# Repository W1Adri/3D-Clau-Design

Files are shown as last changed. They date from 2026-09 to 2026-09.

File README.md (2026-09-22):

# CLAU — Modelo 3D y análisis volumétrico

Modelo 3D paramétrico del CubeSat 6U **CLAU** (*CubeSat Làser per a Aplicacions
Ultrasegures*), de la asociación **ACSAR** (EETAC, UPC).

## La misión en pocas líneas

CLAU demostrará **distribución cuántica de claves (QKD)** desde órbita baja hacia
la estación óptica terrestre **ESA OGS Teide** (telescopio de 1 m). Protocolo
**BB84 con estados señuelo (decoy)**, codificación en **polarización**, a
**1550 nm**.

**Arquitectura "opción B"** (19-09-2026): el transmisor BB84 se construye con
componentes de **fibra comerciales** — láser DFB pulsado más moduladores de
niobato de litio —, **sin chip fotónico (PIC) en vuelo** y **sin canal óptico
clásico**. El canal clásico para el post-procesado de la clave va por **radio en
banda S**.

Quedan **fuera** de la arquitectura, y por tanto fuera de este modelo: CubeCAT,
el módulo cuántico integrado tipo QUBE y el PIC.

## Qué hace este repositorio y por qué

La prioridad es el **análisis volumétrico**: responder con números, y no con
intuición, a si el payload cabe en 6U y dónde queda el hueco libre. Sobre esa
base, el repositorio:

1. **Informe de volumen** — tabla por componente (volumen, posición, estado del
   dato), volumen libre en cm³ y en U, y un mapa de dónde está ese hueco.
2. **Test de interferencias** — falla si dos sólidos se solapan, si algo sale de
   la envolvente 6U o si invade un *keep-out*.
3. **Test de conexiones** — falla si una conexión apunta a un componente que no
   existe o sin espacio para el conector.
4. **Presupuestos de masa y potencia** — separando lo confirmado de lo que no lo
   está, sin rellenar huecos.
5. **Vistas renderizadas** — con los TBD a la vista, en su propio color.

Todo se regenera con **un solo comando** (`uv run clau3d todo`). No hay ningún
número escrito a mano en ningún informe.

## Regla principal: ningún número inventado

**Todas** las dimensiones, masas y consumos viven en un único fichero,
`data/components.yaml`. No hay literales repartidos por el código. Cada magnitud
es un bloque con **valor, unidad, fuente y estado**:

| estado | significado |
|---|---|
| `confirmado` | Sale de la ficha técnica o de la norma **del componente elegido**. |
| `referencia` | Sale de un componente **parecido**, no del elegido. Sirve para reservar volumen, no para cerrar el diseño. |
| `decision` | Decisión de diseño de ACSAR. No procede de ninguna ficha. |
| `supuesto` | Número **inventado aquí** para poder dibujar la pieza. No sale de ninguna fuente: `fuente` lleva el razonamiento. Exige además `falta` y `pedir_a`, como un TBD. |
| `TBD` | Falta el dato **y no hay aproximación defendible**. El valor es `null` y es **obligatorio** decir qué falta y a quién pedirlo. |

Cuatro consecuencias, y las cuatro son tests que fallan si se incumplen:

- **Un hueco se queda como hueco.** Una magnitud `TBD` no puede tener valor. No
  se rellena con nada "razonable" **sin marcarlo**.
- **Un número inventado se declara como inventado.** Eso es `supuesto`, y tiene
  precio: **no suma** en los presupuestos de masa ni de potencia, se dibuja en
  gris y sale en la lista de pendientes junto a los TBD, con el valor concreto
  que hay que sustituir. La diferencia con TBD no es si el dato está, es si la
  pieza se puede dibujar.
- **Si dos fuentes discrepan, se guardan las dos.** El campo `alternativas`
  conserva la cifra que no se usa, con su fuente y el porqué. Están en
  `reports/06_pendientes.md`.
- **Lo que no se puede comprobar, se dice.** Un chequeo sin datos sale como
  `no comprobable`, nunca como correcto.

En los renders, el **estado manda sobre la categoría**:

| color | significado |
|---|---|
| **magenta** | `TBD` — falta el dato |
| **naranja** | `referencia` — componente parecido, no el elegido |
| **azul** | `decision` — decisión de diseño |
| **gris**, más transparente | `supuesto` — número inventado aquí, solo reserva sitio |
| color de su categoría | `confirmado` |

## Instalación y uso

Requiere [`uv`](https://docs.astral.sh/uv/) (igual que el resto de repos del
proyecto). Python 3.12: **CadQuery/OCP aún no tiene ruedas para 3.14**, y `uv` se
encarga de descargar la versión correcta.

```bash
git clone https://github.com/W1Adri/3D-Clau-Design.git
cd 3D-Clau-Design
uv sync
```

| Orden | Qué hace |
|---|---|
| `uv run python tools/generar_layout.py` | Regenera `data/layout.yaml` desde el catálogo. |
| `uv run clau3d validar` | Comprueba la integridad del catálogo (estados, fuentes, TBD, conexiones). |
| `uv run clau3d piezas` | Exporta cada pieza generada a `cad/generated/*.step`. |
| `uv run clau3d ensamblar` | Exporta el ensamblaje completo a `cad/generated/clau_6u.step` y **un STEP por subsistema** en `cad/generated/subsistemas/`. |
| `uv run clau3d informe` | Regenera todo `reports/`: informes, vistas y `components_status.csv`. Devuelve **1** si hay choques de geometría o chequeos críticos; una invasión de keep-out supuesto **no** cuenta. |
| **`uv run clau3d ver`** | **Abre el visor interactivo en `http://localhost:8000`.** |
| **`uv run clau3d todo`** | **Las cuatro primeras, de una vez.** |
| `uv run pytest` | Tests de datos, estructura, interferencias, conexiones y viabilidad. |

## Cómo se mira el modelo: `clau3d ver`

```bash
uv run clau3d ver
```

Levanta un servidor en `http://localhost:8000` y abre el navegador. Es la forma
normal de mirar el satélite: órbita con el botón izquierdo, *pan* con el
derecho, zoom con la rueda.

| Panel | Qué da |
|---|---|
| **Modelo** | Capas (estructura, raíles, zonas, keep-outs, ejes, aristas), plano de **corte** por X, Y o Z, y el árbol de piezas agrupado por zona, con el volumen libre de cada una. |
| **Datos** | De la pieza seleccionada: cada cota **con su estado y su fuente**, los TBD con a quién hay que pedirlos, y las discrepancias con las dos cifras. Debajo, volumen por zona y totales. |
| **Avisos** | Los quince chequeos de viabilidad y las interferencias, con el mismo criterio que `reports/`: *no comprobable* nunca sale como *ok*. |

Los botones **ISO / Planta / Alzado / Perfil** encuadran las mismas vistas que
`reports/vistas/`. Al pinchar una pieza se resalta y se abre su ficha.

Dos cosas que el visor deja claras a propósito:

- El color dice **de dónde sale el dato**, no qué es la pieza: magenta = falta el
  dato, naranja = dato de un componente parecido, azul = decisión de ACSAR. Solo
  las cotas confirmadas se colorean por categoría.
- La lista **Sin geometría** enseña los componentes que no se pueden dibujar,
  con a quién hay que pedirles la envolvente. Por eso el hueco libre aparece
  marcado como *(techo)*: no es una cifra de diseño.

Mientras el visor está levantado **se regenera solo**. Si editas
`data/*.yaml` o dejas un STEP nuevo en `cad/vendor/`, basta recargar el
navegador: el servidor rehace el GLB y la escena antes de servirlos.

Opciones: `--puerto N` (si está ocupado coge el siguiente libre) y `--sin-abrir`
(no lanza el navegador, solo imprime la dirección).

> El visor necesita conexión a internet la primera vez de cada sesión: carga
> three.js desde un CDN. Todo lo demás —geometría, cotas, informes— sale del
> repositorio.

## Cómo se abre el resultado en FreeCAD

1. `uv run clau3d ensamblar` genera `cad/generated/clau_6u.step`.
2. En FreeCAD: **Archivo → Abrir** y elegir ese `.step`.

El ensamblaje se exporta con **nombres y colores por pieza**, así que en el árbol
del modelo aparece cada componente con su `id` del catálogo y su color de estado.
Los sólidos son geometría B-Rep estándar: no hace falta ningún complemento.

Las piezas sueltas de `cad/generated/` se abren igual, y se pueden reimportar en
este repositorio exactamente como los STEP de fabricante.

## Los dos orígenes de geometría

```
cad/vendor/      STEP de fabricante y del equipo — NO se tocan
cad/generated/   STEP generados por este repositorio
```

Cada componente puede estar en **cualquiera de los dos estados** sin que cambie
nada más del ensamblaje.

### Añadir un STEP de fabricante y sustituir una caja envolvente

1. Copiar el fichero a la carpeta de su proveedor dentro de `cad/vendor/`,
   p. ej. `cad/vendor/aac_clyde_space/adcs_iadcs400.step`. Hay una carpeta por
   proveedor y `cad/vendor/README.md` dice cuál es cuál.
2. En `data/components.yaml`, en el bloque `forma` de ese componente, añadir el
   bloque `step:`. **Un STEP lleva procedencia, igual que un número**: sin
   `estado` y `fuente`, `clau3d validar` falla.

   ```yaml
     - id: adcs_iadcs400
       forma:
         tipo: step
         step:
           ruta: cad/vendor/aac_clyde_space/adcs_iadcs400.step
           estado: referencia      # 'confirmado' solo con el part number verificado
           fuente: De donde salio el fichero y quien lo paso
           orientacion: [0, 0, 90] # si viene con otros ejes; no cambia ninguna cota
         dimensiones:              # se conserva como referencia de ficha
           valor: [95.4, 95.9, 67.3]
           unidad: mm
           estado: confirmado
           fuente: ...
   ```

3. Anotar su SHA-256 en `cad/vendor/MANIFEST.yaml` y `uv run clau3d todo`.

A partir de ahí la caja desaparece y el modelo usa la geometría real: el
ensamblaje, las interferencias y el volumen se recalculan solos. **No hay que
tocar el código ni la distribución.**

### Reservar el sitio de un STEP que todavía no ha llegado

De los ficheros que faltan ya se sabe **quién los tiene y de qué producto son**,
así que la procedencia se puede escribir por adelantado con `step_esperado`:

```yaml
  - id: telescopio_cassegrain
    forma:
      tipo: cassegrain
      step_esperado:
        ruta: cad/vendor/aperture_optical_sciences/telescopio_cassegrain.step
        pedir_a: Oscar (ACSAR) / Aperture Optical Sciences
        fuente_prevista: Telescopio Cassegrain de Aperture Optical Sciences
      dimensiones:            # la reserva, mientras tanto
        valor: [95.4, 95.4, 200.0]
        estado: supuesto
        ...
```

**Dejar el fichero en esa ruta basta**: sustituye al modelo aproximado sin tocar
el catálogo. Entra como `referencia`, porque que aparezca donde se esperaba no
verifica su part number, y el chequeo `step_de_fabricante` recuerda que hay que
verificarlo. Lo que **no** existe es importar cualquier fichero que se llame
como el componente: un STEP sin procedencia es lo mismo que un número sin
fuente.

Cuando llegue el **chasis 6U del equipo**, sustituye al genérico por el mismo
camino, y además desaparece la hipótesis de espesor de pared (ver más abajo).

## Estructura del repositorio

```
data/components.yaml    dimensiones, masas, consumos, fuentes y estado
data/connections.yaml   conexiones ópticas, RF, datos, potencia y térmicas
data/layout.yaml        distribución dentro del 6U (GENERADO, no editar)
tools/generar_layout.py genera data/layout.yaml desde el catálogo
src/clau3d/             modelo de datos, piezas, ensamblaje, análisis, informes
src/clau3d/optica/      modelo parametrico del telescopio Cassegrain
src/clau3d/visor/       pagina del visor web (clau3d ver)
tests/                  209 tests: datos, formas, supuestos, keep-outs, STEP, visor, telescopio, beacons, cadena optica, banco y bandeja
cad/vendor/             STEP de fabricante, una carpeta por proveedor (no se tocan)
cad/generated/          STEP generados: uno por pieza, mas el ensamblaje completo
cad/generated/subsistemas/  un STEP por subsistema, con las coordenadas del conjunto
reports/                informes, vistas y components_status.csv (generados)
CLAUDE.md               estado, decisiones y razonamiento de la distribución
```

**Un STEP de subsistema que lleve dentro una pieza dibujada con CAD de
fabricante *contiene* ese CAD**, y este repositorio es público. El sufijo
`_con_cad_de_fabricante` lo pone el exportador mirando lo que ha metido —no una
lista a mano, que se quedaría obsoleta con el siguiente STEP de proveedor— y el
`.gitignore` ignora ese sufijo.

## Estado actual

- **Norma**: CubeSat Design Specification **Rev. 14.1** (2022-02-09), que
  sustituye a la Rev. 13 y a la 6U CDS Rev 1.0. Envolvente 6U del plano
  CDS-14-007: **226.3 × 100.0 × 366.0 mm**, masa máxima 12.00 kg.
- **38 componentes** en el catálogo, **35 con envolvente**. Los tres que no la
  tienen son el UHF de respaldo y el módulo de propulsión (los dos opcionales y
  sin decidir) y los coaxiales RF, que no son un cuerpo sino un keep-out.
- **63 huecos sin aproximación** (`TBD`), **78 números inventados aquí**
  (`supuesto`) y **10 discrepancias** entre fuentes.
- **Distribución confirmada** (2026-09-20): **dos columnas de 3U** a lo largo de
  todo Z — plataforma en −X, payload en +X. `data/layout.yaml` no se escribe a
  mano: lo genera `tools/generar_layout.py` desde el catálogo. **Repartida otra
  vez el 2026-09-21** (`CLAUDE.md` §3.11): el telescopio pasa a los **227 mm**
  que son los «~2U» de verdad del brief, y esos 27 mm salen de la bandeja, que
  los tenía de sobra, y van a la franja, que no.
- **31 piezas colocadas, todas**, y **0 choques de geometría**. `camara_beacon`
  y `mod_fase_mpz_ln_10`, que no cabían, ya tienen sitio, así que **`clau3d
  informe` devuelve 0** por primera vez desde que se dibuja el payload entero.
- **24 keep-outs**, todos dibujados con números supuestos, porque las tres cotas
  que los dimensionan —radio de curvatura de la fibra, el del coaxial y el
  diámetro de haz— siguen siendo TBD. Hay 13 invasiones, **todas del radio de
  curvatura**, y el informe las separa de los choques de geometría porque **no
  son lo mismo**: dicen "con la hipótesis de hoy, aquí no cabe".
- Zona útil interior **221.7 × 95.4 × 361.4 mm = 7.64 L**, de la que quedan
  **2.65 L libres**. Era 5.84 L cuando 19 componentes no ocupaban nada; la
  cifra de antes no era mejor noticia, era menos información.

### Lo que ya aprieta, con números

| Hallazgo | Número |
|---|---|
| La apertura de 90 mm del telescopio contra la altura interior | Deja **2.7 mm hasta la cara plana** y **22.5 mm hasta la esquina**. Por eso el barrilete se modela de sección **cuadrada**: en la cara plana solo caben pared, baffle y holgura, y la celda del primario y los largueros estructurales tienen que ir en las esquinas. El eje óptico no puede ir paralelo a Y. Falta el **contorno exterior del barrilete**. |
| La longitud del telescopio contra los **227 mm** reservados | Con el haz en 7 mm la separación entre vértices del afocal (`f1·(1−1/M)`) sube a **184.4 mm** y el modelo cabe con **21.6 mm** de margen. Con los 200 mm de antes cabía por 1.2, que no era margen: los espesores con los que se dibuja están todos en su cota superior y ahora tienen sitio para crecer hasta ser reales. **Peor caso**: si el haz bajara a 3.54 mm —el único con el que el MEMS del FSM seguiría en juego— quedarían 13.9 mm. |
| El haz comprimido contra el espejo del FSM y contra las ópticas del banco | Un haz de *d* mm a 45° deja una huella de *d* × *d*·√2. El espejo de **5 mm** del MEMS solo admite **3.54 mm**; una óptica de **Ø12.7** (apertura libre 11.4) admite **8.06 mm**. Con el haz supuesto de **7 mm** las ópticas del banco valen —y son las que hacen que el brazo de los beacons quepa— pero **el MEMS no**: habría que ir al piezo (130 g) o bajar el haz a 3.54, que alarga el tubo. El diámetro de haz real es TBD, y es **el dato que decide qué FSM se elige**. |
| El **iADCS400** (95.4 mm de lado corto) dentro de los 100 mm exteriores | El espesor de pared no puede pasar de **2.30 mm**. Es la pieza que más aprieta, por delante del contorno PC104 desnudo, que daba 4.91 mm. |
| Moduladores Exail de **grado espacial** | **130 mm** de recorrido recto cada uno, protectores de fibra incluidos. Es **45 mm más largo** que la cifra del encapsulado comercial. En la columna de payload, de 121.7 mm de ancho, **no caben según X**: van según Z. |
| Longitud de la pila PC104 | **305 mm de 361 mm**, con el paso estándar PC/104 de 15.24 mm. Eran 274 hasta descubrir que las ranuras se reservaban con la altura de **ficha** y se dibujaban con el **STEP**: las fichas de AAC no incluyen el conector PC104 pasante, que baja 12.45 mm. El paso **real** del chasis sigue siendo TBD, y ahora el margen es la mitad. |
| El banco óptico, en la línea que va del eje del telescopio a la pared | **26.7 mm** de margen: eran 7.7 con el colimador en la fila, 15.7 cuando salió y 26.7 desde que las celdas de D1 y del espejo bajan a 16 mm (Ø12.7). El FSM tiene que estar sobre el eje óptico porque es el que dobla el haz, y eso deja a D1 y al espejo de plegado en fila con él: 74.0 mm para 47.3 mm de piezas. Las envolventes que lo llenan siguen siendo **supuestas**. |
| El tramo recto que alimenta al colimador, en Z | **CABE con 9.0 mm** desde que el telescopio reserva 227. Después del codificador de polarización la fibra no se puede curvar, así que el colimador (28), el protector del empalme (60) y el codificador (130) van **en fila**: 218 mm en una franja de 227, que antes eran 200 y faltaban 18. Alargar el banco **no habría ayudado** —la cuenta es de la franja—. Siguen abiertas dos salidas que darían más: salida colimada de fábrica de Exail (+42) y recubrir el empalme en vez de protegerlo (+22). |
| El brazo de los beacons, en la línea que va de D1 a la pared en Y | **CABE con 11.7 mm** desnudo y 1.7 colocando. Los dos beacons comparten un brazo y dentro de él un segundo dicroico los separa: semi-D1 (8) + D2 (16) + colimador del beacon (12) = 36 mm para 47.7. Antes faltaban 6.8 y la cámara no se colocaba; lo arreglan las ópticas de Ø12.7, invertir D2 para llevar la cámara a la rama −X y partir el láser de bajada en módulo (bandeja) y colimador (banco). |
| La cámara de beacon contra el FSM | **0.45 mm**, y es el sitio más apretado del payload. Va centrada en el eje de D2, a 21 mm del plano óptico, y su semisección son 13: la cara inferior cae en Y = +8.0 y el FSM llega a +7.55. Por eso su sección es 26 mm y no 30: con 30 hay solape real. Si el sensor elegido pide más, hay que mover el brazo, no apretar la reserva. |
| Bucles de fibra | **No comprobable**: falta el radio mínimo de curvatura. Con el valor supuesto de 30 mm, la bandeja **no cumple**. Es el dato que más desbloquea del proyecto. Lo que ya **no** depende de él es el colimador: su latiguillo dejó de existir al reordenar la cadena. |
| La antena de banda S | **No hay cara libre**. +Z la ocupan el telescopio y el star tracker, contra ±X y ±Y la pila deja 2–3 mm, y sus 10 mm de espesor no caben en los 6.5 mm de protrusión que permite la CDS. Acaba en −Z, apuntando al lado contrario que el telescopio: es una decisión de operaciones sin tomar. |

## Decisiones de diseño tomadas

- **CadQuery** como núcleo del modelado, con exportación a STEP. No se usa
  build123d: CadQuery cubre todo lo que hace falta aquí y es la dependencia más
  ligera. Nada de Onshape ni Fusion 360.
- **El layout es un dato, no código.** Cambiar la distribución es editar
  `data/layout.yaml`; el modelo, los tests y los informes se recalculan solos.
- **El estado del dato manda sobre la categoría** en el color de los renders: lo
  que falta se ve antes que lo que está.
- **Distribución: dos columnas de 3U** a lo largo de todo Z (2026-09-20).
  Plataforma en −X con la pila PC104 completa; payload en +X repartido en
  telescopio / banco de espacio libre / bandeja de fibra. Razonamiento y
  contrapartidas en `CLAUDE.md` §3.
- **El layout se genera, no se escribe.** `tools/generar_layout.py` calcula cada
  coordenada desde `data/components.yaml` y el paso PC/104. Cuando llegue una
  dimensión nueva, se regenera; no se recalcula a ojo.
- **Espesor de pared = 2.3 mm** como hipótesis única de trabajo, y es el **mayor
  espesor compatible con todas las piezas conocidas**: lo fija el iADCS400, que
  al ser tarjeta apilada no se puede tumbar y necesita 95.4 mm de los 100 mm
  exteriores. Da el **menor volumen útil posible**, así que todo volumen libre
  que salga de aquí **se queda corto, nunca se pasa**. El chequeo
  `seccion_componentes` recalcula esta cota desde el catálogo y avisa si deja de
  ser válida. Desaparece en cuanto llegue el chasis del equipo.
- **Paso de apilamiento modelado = 15.24 mm**, el estándar PC/104 (0.600 in).
  Una tarjeta más alta que el paso ocupa `ceil(altura / paso)` posiciones de
  separador. El paso real del chasis sigue siendo TBD.
- **Para los moduladores se usa la cifra de grado espacial**, no la comercial:
  es el encapsulado que vuela. La comercial queda registrada como alternativa.
- **Se modelan 2 baterías Optimus-30** solo para reservar volumen. El número real
  es TBD y depende del presupuesto de energía.

## Decisiones que siguen abiertas

- **Diámetro exterior y longitud real del telescopio.** Decide si el payload
  cabe. La distribución le reserva **227 mm**, que son los «~2U» del brief con
  la U de longitud de la CDS (113.5 mm); lo que falta es el contorno.
- **Cómo se encamina la potencia del láser** (4.1 W): directa del bus del EPS o
  a través de PCB-2.
- **FSM**: MEMS tipo Mirrorcle (herencia CLICK-A) frente a piezo PI S-331. Las
  dos familias tienen envolventes muy distintas, y desde que el haz modelado
  baja a 7 mm **ya no es una elección libre**: el espejo de 5 mm del MEMS no
  admite esa huella. O el haz baja a ≤ 3.54 mm —y el tubo se alarga— o el MEMS
  queda descartado.
- **El diámetro de haz comprimido**, que es lo que decide lo anterior. Hoy se
  dibuja con 7 mm, que no es una medida: es el **techo** que impone la familia
  de ópticas Ø12.7 del banco, la única con la que el brazo de los beacons cabe.
- **La apertura libre real de las monturas del banco**, que es de donde sale ese
  techo (11.4 mm supuestos para Ø12.7).
- **Qué par de bases usa el enlace**: D/A + R/L sin lámina, o H/V + D/A con una
  λ/4 fija. Los dos valen para BB84, así que la decide la estación de tierra.
- **Si la guía del MPZ-LN-10 transmite las dos polarizaciones.** Si no —si es de
  intercambio protónico— el esquema de codificación con un solo modulador de
  fase es imposible, y la arquitectura del transmisor cambia entera.
- **El aislamiento de la cámara a 1064 nm.** Es el número que sostiene la
  elección de longitudes de onda (976 arriba, 1064 abajo, por la ceguera del
  silicio a 1064) y hoy no está medido.
- **Si el cuarto puerto de D2 se instrumenta** con un fotodiodo de monitor del
  beacon o se tapa con una trampa de luz. Lo que no es opción es dejarlo
  abierto.
- **Formato PC104 para las tres PCBs propias.** Está propuesto, no confirmado.
- **Número de módulos de batería** y **configuración de paneles PHOTON**.
- **Starbuck-Nano-PLUS frente a Starbuck-Nano**: la ficha describe el PLUS para
  plataformas con **paneles desplegables**, y CLAU parte de paneles de montaje en
  cuerpo. A revisar con AAC.
- **Propulsión**: opcional, prioridad baja, entre 0.1U y 1U.
- **Radio UHF Pulsar-VUTRX**: opcional, solo si queda volumen.

## Lista de pendientes

No hay copia aquí, a propósito: se quedaba obsoleta en cuanto cambiaba el
catálogo, que es cada commit. Lo que hay es dónde está, siempre al día:

| dónde | qué lleva |
|---|---|
| `reports/06_pendientes.md` | Todos los huecos, agrupados **por a quién hay que pedírselos**. Separa los `TBD` (sin aproximación) de los `supuesto` (dibujados, pero inventados), y de cada supuesto dice el valor concreto que hay que sustituir. |
| `reports/components_status.csv` | Una fila por componente, para **actualizar la hoja índice de Drive**: `id_drive`, de dónde sale el sólido que se dibuja, el estado y la fuente de las cotas, los conectores, los keep-outs, qué falta y a quién. Un `id_drive` vacío significa que esa pieza no está en la hoja. |
| `reports/01_viabilidad.md` | Los chequeos, con los `no comprobable` diciendo qué dato les falta. |

Se regeneran con `uv run clau3d informe`.

### Los que más desbloquean

1. **El radio mínimo de curvatura de la fibra** (equipo de payload). Las 7
   invasiones de keep-out del modelo salen de él.
2. **El diámetro del haz comprimido** (equipo de óptica). De él salen la
   magnificación del telescopio y con ella su geometría entera, y decide si el
   FSM puede ser el MEMS de 5 mm o tiene que ser el piezo.
3. **El STEP del telescopio** (Óscar / Aperture Optical Sciences). Hay sitio
   reservado: dejarlo en `cad/vendor/aperture_optical_sciences/telescopio_cassegrain.step`
   basta para que sustituya al modelo paramétrico, sin tocar el catálogo.
4. **El paso de apilamiento real del chasis** (equipo de estructura). El margen
   de la pila se ha quedado en 56 mm.
5. **Las alturas reales de PCB-1, PCB-2 y PCB-3** (equipo de electrónica).
   Ahora se dibujan con 15 mm supuestos.
6. **La decisión sobre el brazo de los beacons** (ACSAR). Es lo único que hoy
   hace que `clau3d informe` devuelva 1.

---

<sub>Los informes de `reports/` y los STEP de `cad/generated/` se generan
automáticamente. No editarlos a mano.</sub>

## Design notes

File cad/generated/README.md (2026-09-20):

# STEP generados

Generados por `uv run clau3d piezas` y `uv run clau3d ensamblar`.
**No editar a mano**: se sobrescriben.

Se reimportan exactamente igual que los de `cad/vendor/`.

## Que se versiona y que no

Los STEP **por pieza** son de unos 15 KB cada uno y se versionan: son cajas
envolventes generadas desde `data/components.yaml`, no contienen nada de nadie.
`escena.json` (~43 KB) tambien.

El **ensamblaje completo** no. Desde que hay geometria de fabricante dentro,
`clau_6u.step` pesa **175 MB** y `clau_6u.glb` **46 MB**, pero el problema no es
el tamano: es que **contienen el CAD de AAC**. Versionarlos seria redistribuirlo
por la puerta de atras, que es justo lo que evita `cad/vendor/.gitignore`. Se
regeneran cuando hagan falta:

```bash
uv run clau3d ensamblar   # clau_6u.step
uv run clau3d ver         # clau_6u.glb + escena.json
```

Una pieza que pasa de caja envolvente a STEP de fabricante **deja de generarse
aqui**, y `exportar_generados()` borra el fichero que hubiera quedado: si no, el
repositorio seguiria ensenando una caja de una pieza que el modelo ya dibuja con
su geometria real.

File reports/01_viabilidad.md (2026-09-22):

# Chequeos de viabilidad

Generado automaticamente el 2026-09-21 por `clau3d informe`.
No editar a mano: los numeros salen de `data/components.yaml`.

- Mision: CLAU - CubeSat Laser per a Aplicacions Ultrasegures
- Norma: CubeSat Design Specification Rev. 14.1, The CubeSat Program, Cal Poly SLO
- Estado del layout: **confirmada** (31 piezas colocadas)

Comprobaciones que no dependen de donde se coloque cada pieza.

## Volumen total frente a la zona util

**Estado: ATENCION**

Los 29 componentes con envolvente conocida ocupan 4531 cm3 de los 7644 cm3 interiores (59%). Quedan 3 componentes sin envolvente: el dato real sera mayor.

| magnitud | valor |
|---|---|
| interior_cm3 | 7643.68 |
| ocupado_conocido_cm3 | 4531.20 |
| libre_si_nada_mas_creciera_cm3 | 3112.48 |
| fraccion_ocupada | 0.59 |
| componentes_sin_volumen | 3 |

Falta: Envolvente de: radio_uhf_pulsar_vutrx, propulsion, cables_rf_moduladores

## Apertura del telescopio frente a la seccion interior

**Estado: ATENCION**

Con seccion CUADRADA de 95.4 mm y 90 mm de apertura quedan 2.7 mm hasta la cara plana y 22.5 mm hasta la esquina. Los dos numeros son el mismo problema visto por dos lados: en la cara plana no cabe nada (pared, baffle y holgura ya se comen esos 2.7 mm), y la celda del primario, los flexures y los largueros estructurales tienen que ir en las esquinas. Con un barrilete de REVOLUCION solo existiria el primer numero, en todas las direcciones. El eje optico NO puede ir paralelo a Y, y en cualquier otra orientacion la seccion util sigue limitada por Y. Si la esquina tampoco bastara, la salida es que el barrilete sea el elemento estructural de esa cara.

| magnitud | valor |
|---|---|
| apertura_libre_mm | 90.00 |
| altura_exterior_mm | 100.00 |
| altura_interior_util_mm | 95.40 |
| holgura_por_lado_mm | 2.70 |
| holgura_cara_plana_mm | 2.70 |
| holgura_esquina_mm | 22.46 |

Falta: Contorno exterior del barrilete (la apertura libre no basta)

## Contorno PC104 frente a la seccion interior

**Estado: ATENCION**

La tarjeta de 95.89 x 90.17 mm cabe en 221.7 x 95.4 mm, pero deja solo 5.23 mm de holgura en Y. El espesor de pared no puede pasar de 4.91 mm, cota mas holgada que la que fija el iADCS400. Ademas, la zona util sale de un modelo de CAJA CON PAREDES de espesor uniforme, y el chasis 6U real es un ARMAZON CON RAILES: el hueco util no es un prisma, varia con Z y con la cara. Este chequeo no sera concluyente hasta sustituir el modelo por el STEP del chasis del equipo.

| magnitud | valor |
|---|---|
| contorno_largo_mm | 95.89 |
| contorno_ancho_mm | 90.17 |
| interior_X_mm | 221.70 |
| interior_Y_mm | 95.40 |
| espesor_pared_supuesto_mm | 2.30 |
| espesor_pared_maximo_mm | 4.91 |

Falta: Zona util real del chasis 6U del equipo (STEP o plano con railes)

## Seccion interior frente a todas las piezas

**Estado: NO COMPROBABLE**

NO CONCLUYENTE. El espesor de pared supuesto (2.30 mm) coincide con el maximo compatible (2.30 mm): el margen es de 0.00 mm. Pero esa cota se DEDUJO de 'adcs_iadcs400', asi que decir que 'adcs_iadcs400' cabe con 0.00 mm de holgura no comprueba nada; es la hipotesis devuelta tal cual. El resto de piezas si tienen holgura real frente a esta seccion, pero la pieza que manda no. Ademas, la zona util sale de un modelo de CAJA CON PAREDES de espesor uniforme, y el chasis 6U real es un ARMAZON CON RAILES: el hueco util no es un prisma, varia con Z y con la cara. Este chequeo no sera concluyente hasta sustituir el modelo por el STEP del chasis del equipo.

| magnitud | valor |
|---|---|
| espesor_supuesto_mm | 2.30 |
| espesor_maximo_compatible_mm | 2.30 |
| interior_X_mm | 221.70 |
| interior_Y_mm | 95.40 |
| interior_Z_mm | 361.40 |
| piezas_que_no_caben | 0.00 |
| margen_de_espesor_mm | 0.00 |

Falta: Zona util real del chasis 6U del equipo (STEP o plano con railes)

## Recorrido recto de Exail MXER-LN-10 (modulador de intensidad, grado espacial EM/NS-FM/FM)

**Estado: OK**

Los 130 mm de recorrido recto solo caben orientados segun X, Z. Esto ya fija la orientacion de la bandeja optica, antes de anadir los bucles de fibra.

| magnitud | valor |
|---|---|
| longitud_con_fibras_mm | 130.00 |
| interior_X_mm | 221.70 |
| interior_Y_mm | 95.40 |
| interior_Z_mm | 361.40 |

## Recorrido recto de Exail MPZ-LN-10 (modulador de fase, codificador de polarizacion)

**Estado: OK**

Los 130 mm de recorrido recto solo caben orientados segun X, Z. Esto ya fija la orientacion de la bandeja optica, antes de anadir los bucles de fibra.

| magnitud | valor |
|---|---|
| longitud_con_fibras_mm | 130.00 |
| interior_X_mm | 221.70 |
| interior_Y_mm | 95.40 |
| interior_Z_mm | 361.40 |

## Longitud de la pila PC104

**Estado: OK**

Con el paso estandar PC/104 de 15.24 mm, las 9 tarjetas de altura conocida ocupan 20 posiciones de separador, o sea 305 mm. Reservando una posicion por cada una de las 1 tarjetas sin altura (15 mm mas), la pila suma 320 mm frente a 361 mm interiores. El paso REAL del chasis sigue siendo TBD: este numero es una estimacion con el paso de la norma, no el del chasis elegido.

| magnitud | valor |
|---|---|
| tarjetas_con_altura | 9.00 |
| suma_alturas_mm | 246.15 |
| interior_Z_mm | 361.40 |
| tarjetas_sin_altura | 1.00 |
| paso_modelado_mm | 15.24 |
| posiciones_de_separador | 20.00 |
| longitud_modelada_mm | 304.80 |
| reserva_tarjetas_sin_altura_mm | 15.24 |

Falta: Paso de apilamiento PC104 del chasis elegido

## Cadena de espacio libre entre el eje del telescopio y la pared

**Estado: OK**

El FSM va sobre el eje optico del telescopio (X = +36.85 mm) porque es el que dobla el haz de X a Z. Del eje a la pared +X de la columna hay 74.0 mm, y la media anchura del FSM mas el D1 mas el espejo de plegado suman 47.3 mm, sin contar holguras de montaje. Quedan 26.7 mm de margen.

| magnitud | valor |
|---|---|
| fsm | 15.29 |
| dicroico_d1 | 16.00 |
| espejo_plegado_cuantico | 16.00 |
| necesario_mm | 47.29 |
| disponible_mm | 74.00 |
| margen_mm | 26.71 |
| camara_beacon_mm | 30.00 |
| margen_-X_D2_mm | 32.99 |
| fotodiodo_monitor_beacon_mm | 12.00 |
| margen_+X_D2_mm | 30.71 |

## El espejo de plegado frente al borde de la franja

**Estado: OK**

El colimador va coaxial con el espejo, en X = +95.55 mm, y con 6.0 mm de radio su cara -X cae en +89.55. La franja empieza en +84.55. Quedan 5.0 mm de margen.

| magnitud | valor |
|---|---|
| x_espejo_mm | 95.55 |
| x_colimador_mm | 95.55 |
| coaxialidad_mm | 0.00 |
| radio_colimador_mm | 6.00 |
| borde_franja_mm | 84.55 |
| x_minimo_del_colimador_mm | 89.55 |
| margen_mm | 5.00 |

## Brazo compartido de los dos beacons, de D1 a la pared del banco

**Estado: OK**

Los dos beacons comparten el brazo que refleja D1, y dentro de el D2 los separa. El reparto por ramas sale de 'meta.topologia_brazo_beacons' de data/connections.yaml, que es el mismo dato que usa el generador para colocar -- +Y: dicroico_d2 + colimador_beacon_bajada; -Y: trampa_luz_d1; -X: camara_beacon; +X: fotodiodo_monitor_beacon. La rama mas apretada es +Y: pide 36.0 mm desde el centro de su divisor y tiene 47.7 mm, sin contar holguras de montaje. Quedan 11.7 mm de margen. Ojo: es el margen DESNUDO. El generador coloca dejando holgura entre pieza y pieza, asi que lo que de verdad sobra en la rama +Y es menos, y todas las envolventes del brazo siguen siendo SUPUESTAS.

| magnitud | valor |
|---|---|
| dicroico_d2_mm | 16.00 |
| colimador_beacon_bajada_mm | 12.00 |
| necesario_+Y_mm | 36.00 |
| disponible_+Y_mm | 47.70 |
| margen_+Y_mm | 11.70 |
| trampa_luz_d1_mm | 15.00 |
| necesario_-Y_mm | 23.00 |
| disponible_-Y_mm | 47.70 |
| margen_-Y_mm | 24.70 |
| camara_beacon_mm | 30.00 |
| necesario_-X_mm | 38.00 |
| disponible_-X_mm | 70.99 |
| margen_-X_mm | 32.99 |
| fotodiodo_monitor_beacon_mm | 12.00 |
| necesario_+X_mm | 20.00 |
| disponible_+X_mm | 50.71 |
| margen_+X_mm | 30.71 |

## Orden de la cadena de fibra frente a las restricciones declaradas

**Estado: OK**

La cadena laser_dfb_1550 -> aislador -> filtro_espectral -> mod_intensidad_mxer_ln_10 -> acoplador_monitor -> voa -> mod_fase_mpz_ln_10 -> colimador cumple las 7 restricciones declaradas. Todo componente de fibra va antes del codificador de polarizacion, y detras de el solo esta el colimador.

| magnitud | valor |
|---|---|
| restricciones | 7.00 |
| piezas_en_la_cadena | 8.00 |
| violaciones | 0.00 |

## Tramo de fibra posterior al codificador de polarizacion

**Estado: NO COMPROBABLE**

El tramo va en fila segun Z y suma 218.0 mm: 130 mm del codificador (protectores de fibra incluidos), 60 mm de protector de empalme y 28 mm de colimador. Cabe en los 227.0 mm de la franja, con 9.0 mm de margen. PERO SI ESA LONGITUD DE FIBRA ES ACEPTABLE NO SE PUEDE DECIR: los estados diagonales no son autoestados de la fibra PM y acumulan una fase que deriva con la temperatura, y cuanta es esa fase depende de 'integracion.fibra.sensibilidad_termica_fase_pm', que es TBD.

| magnitud | valor |
|---|---|
| codificador_mm | 130.00 |
| protector_empalme_mm | 60.00 |
| colimador_mm | 28.00 |
| necesario_mm | 218.00 |
| disponible_mm | 227.00 |
| margen_mm | 9.00 |

Falta: integracion.fibra.sensibilidad_termica_fase_pm (medida)

## Eje de fibra del codificador frente al plano optico del banco

**Estado: OK**

El eje de fibra del codificador cae en Y = +0.00 mm y el plano optico del banco -- el del colimador, D1, el FSM y el telescopio -- esta en Y = +0.00 mm. Desvio: 0.00 mm, contra una tolerancia SUPUESTA de 0.50 mm. El tramo puede ser recto sin cambiar de altura.

| magnitud | valor |
|---|---|
| eje_codificador_Y_mm | 0.00 |
| plano_optico_Y_mm | 0.00 |
| desvio_mm | 0.00 |
| tolerancia_mm | 0.50 |

## Configuracion optica del telescopio

**Estado: OK**

Afocal tipo Mersenne: dos parabolas confocales, M = 12.86. Entra colimado y sale colimado, asi que NO hay foco real dentro del satelite y no hace falta ninguna lente de enfoque en el banco. El foco comun de las dos conicas es VIRTUAL y por eso el modelo no dibuja ningun marcador ahi: no hay nada. Obstruccion lineal 0.109 (secundario de 9.8 mm sobre 90 mm). Cuesta 0.05 dB de potencia recogida y 0.10 dB de intensidad en el eje en campo lejano. Son DOS magnitudes distintas, las dos en potencia, y para un enlace optico manda la segunda: lo que llega al receptor es la intensidad en el eje.

| magnitud | valor |
|---|---|
| magnificacion | 12.86 |
| focal_primario_mm | 200.00 |
| focal_secundario_mm | 15.56 |
| separacion_mm | 184.44 |
| obstruccion_lineal | 0.11 |
| perdida_potencia_recogida_dB | 0.05 |
| perdida_intensidad_en_eje_dB | 0.10 |

## Longitud del telescopio frente a la reservada

**Estado: OK**

Con f1 = 200 mm y M = 12.86 la separacion entre vertices es 184.4 mm, que no se puede tocar sin cambiar la optica. Para los 227 mm reservados eso deja 42.6 mm para los dos mamparos, la celda y los dos espejos. Quedan 21.6 mm de margen. PEOR CASO EN LONGITUD: si el haz bajara a 3.54 mm -- el maximo que admite el espejo del FSM MEMS, o sea el unico haz con el que ese FSM seguiria en juego -- la separacion subiria a 192.1 mm y el margen quedaria en 13.9 mm. Un haz mas fino no ahorra tubo: lo alarga, porque sube la magnificacion.

| magnitud | valor |
|---|---|
| longitud_reservada_mm | 227.00 |
| separacion_vertices_mm | 184.44 |
| estructura_mm | 42.56 |
| longitud_necesaria_mm | 205.44 |
| margen_mm | 21.56 |
| focal_primario_mm | 200.00 |
| magnificacion | 12.86 |
| peor_caso_haz_mm | 3.54 |
| peor_caso_separacion_mm | 192.14 |
| peor_caso_margen_mm | 13.86 |

## El haz comprimido frente al espejo del FSM

**Estado: NO COMPROBABLE**

El espejo del FSM mide 5.0 mm, y un haz a 45 grados deja una huella de d x d*raiz(2), asi que solo admite un haz de 3.54 mm. Con 90 mm de apertura eso exige una magnificacion de al menos 25.5. Con el haz SUPUESTO con el que se dibuja (7 mm, de integracion.optica.diametro_haz_modelado) la huella seria 7 x 9.9 mm y NO CABRIA en el espejo de 5 mm. Si el equipo de optica confirma un haz de ese orden, el MEMS DIP24 queda descartado y hay que ir al 'fsm_piezo_pi_s331' (que pesa 130 g frente a los gramos del MEMS) o subir la magnificacion de 12.9 a 25.5, lo que reduce el secundario y alarga el tubo. Punto de adelanto: 50.7 urad en el cielo son 652 urad opticos en el haz comprimido (326 urad de giro mecanico del espejo) con M = 12.86, porque un afocal comprime los angulos por M. Es poco para cualquiera de las dos tecnologias -- el piezo S-331 da 3 mrad --, asi que el recorrido NO es lo que decide: lo que decide es el tamano del espejo.

| magnitud | valor |
|---|---|
| diametro_espejo_fsm_mm | 5.00 |
| haz_maximo_admisible_mm | 3.54 |
| magnificacion_minima | 25.46 |
| magnificacion_modelada | 12.86 |
| haz_modelado_mm | 7.00 |
| huella_a_45_mm | 9.90 |
| punto_de_adelanto_urad | 50.70 |
| recorrido_optico_en_el_fsm_urad | 651.86 |
| giro_mecanico_en_el_fsm_urad | 325.93 |

Falta: Diametro del haz comprimido (telescopio_cassegrain.optica.diametro_haz_comprimido y diametro_haz_mm de e01..e05). Es el dato que DECIDE el TBD 'fsm.eleccion_de_tecnologia': sin el no se puede elegir entre el MEMS y el piezo.

## El haz frente a la apertura libre de las opticas del banco

**Estado: NO COMPROBABLE**

D1, D2 y el espejo de plegado estan a 45 grados, y un haz de 7.0 mm deja sobre ellos una huella de 7.0 x 9.9 mm. La apertura libre de la familia con la que se dimensionan sus celdas es 11.4 mm, o sea que admite un haz de hasta 8.06 mm. Con el haz SUPUESTO con el que se dibuja cabe, con 1.5 mm de margen sobre la apertura, PERO ESO NO VALIDA NADA: los dos numeros son supuestos y el de arriba es el que se eligio para que esto saliera bien. Lo que este chequeo dice de verdad es cual es el TECHO: si el diseno optico pide mas de 8.06 mm de haz, las celdas de 16 mm de D1, D2 y el espejo dejan de valer y hay que rehacer el brazo.

| magnitud | valor |
|---|---|
| haz_modelado_mm | 7.00 |
| huella_a_45_mm | 9.90 |
| apertura_libre_optica_mm | 11.40 |
| haz_maximo_admisible_mm | 8.06 |
| margen_mm | 1.50 |
| celda_dicroico_d1_mm | 16.00 |
| celda_dicroico_d2_mm | 16.00 |
| celda_espejo_plegado_cuantico_mm | 16.00 |

Falta: Apertura libre real de las monturas elegidas para D1, D2 y el espejo de plegado, y el diametro de haz de verdad (telescopio_cassegrain.optica.diametro_haz_comprimido)

## Placa de la bandeja frente a su zona

**Estado: OK**

La zona de la bandeja mide 121.7 x 79.4 mm en X y Z, asi que con 2 mm de holgura por lado la placa tiene que medir 117.7 x 75.4. Mide 117.7 x 75.4. Coincide: el contorno de la placa sigue derivado de su zona. El espesor (3 mm) sigue siendo SUPUESTO, y eso no lo arregla este chequeo.

| magnitud | valor |
|---|---|
| placa_X_mm | 117.70 |
| placa_Z_mm | 75.40 |
| zona_X_mm | 121.70 |
| zona_Z_mm | 79.40 |
| holgura_por_lado_mm | 2.00 |
| derivado_X_mm | 117.70 |
| derivado_Z_mm | 75.40 |
| margen_X_mm | -0.00 |
| margen_Z_mm | -0.00 |

## Radio minimo de curvatura de la fibra

**Estado: NO COMPROBABLE**

Sin radio minimo de curvatura no se puede dimensionar la bandeja optica ni comprobar ningun bucle. Es el parametro que mas area consume de toda la bandeja. Mientras tanto, los keep-outs se dibujan con un radio SUPUESTO de 30 mm y un tramo recto de 20 mm, o sea 50 mm reservados por puerto. Con esa hipotesis la bandeja NO cumple: ver las invasiones de keep-out en el informe de interferencias. Eso no es un fallo del reparto, es lo que cuesta no tener el dato: si el radio real resulta ser la mitad, la mayoria de esas invasiones desaparecen solas.

| magnitud | valor |
|---|---|
| radio_supuesto_mm | 30.00 |
| boot_supuesto_mm | 20.00 |
| reserva_por_puerto_mm | 50.00 |

Falta: Radio minimo de curvatura de la fibra elegida

## Presupuesto de masa

**Estado: ATENCION**

Masa conocida 846 g de un limite de 12000 g (CDS 14.1). Faltan 30 componentes por pesar, incluido el chasis y el telescopio, que son de los mas pesados.

| magnitud | valor |
|---|---|
| masa_conocida_g | 845.90 |
| limite_g | 12000.00 |
| margen_g | 11154.10 |
| componentes_sin_masa | 30.00 |

Falta: Masa de: estructura_6u, adcs_iadcs400, antena_quasar_wsant, radio_uhf_pulsar_vutrx, paneles_photon_side, propulsion, telescopio_cassegrain, fsm, dicroico_d1, dicroico_d2, camara_beacon, laser_beacon_bajada, colimador_beacon_bajada, fotodiodo_monitor_beacon, trampa_luz_d1, espejo_plegado_cuantico, colimador, bandeja_optica, laser_dfb_1550, mod_intensidad_mxer_ln_10, mod_fase_mpz_ln_10, voa, aislador, filtro_espectral, acoplador_monitor, pcb1_control_qkd, pcb2_drivers_opticos, pcb3_pat, cables_rf_moduladores, qrng_idq20mc1_s3

## STEP de fabricante frente al manifiesto

**Estado: ATENCION**

4 de 4 CAD de fabricante presentes y con la huella del manifiesto. 1 pieza espera un STEP que aun no ha llegado; mientras tanto se dibuja con su envolvente aproximada. Dejar el fichero en la ruta indicada basta para que el modelo lo use: telescopio_cassegrain -> cad/vendor/aperture_optical_sciences/telescopio_cassegrain.step (a Oscar (ACSAR) / Aperture Optical Sciences).

| magnitud | valor |
|---|---|
| declarados | 4.00 |
| presentes | 4.00 |
| ausentes | 0.00 |
| huella_distinta | 0.00 |
| sin_declarar | 0.00 |
| esperando_step | 1.00 |
| aparecidos_sin_verificar | 0.00 |

Falta: STEP por recibir: telescopio_cassegrain (a Oscar (ACSAR) / Aperture Optical Sciences)

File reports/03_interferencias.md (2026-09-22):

# Interferencias

Generado automaticamente el 2026-09-21 por `clau3d informe`.
No editar a mano: los numeros salen de `data/components.yaml`.

- Mision: CLAU - CubeSat Laser per a Aplicacions Ultrasegures
- Norma: CubeSat Design Specification Rev. 14.1, The CubeSat Program, Cal Poly SLO
- Estado del layout: **confirmada** (31 piezas colocadas)

Piezas colocadas: **31**. Choques de geometria: **0**. Invasiones de keep-outs dibujados con numeros SUPUESTOS: **13**.

## Choques de geometria

Dos solidos que ocupan el mismo sitio, o una pieza que se sale de donde tiene que estar. Esto si es un error del modelo o del reparto, y hace que `clau3d informe` devuelva codigo 1.

_(sin filas)_

## Invasiones de keep-outs SUPUESTOS (13)

> **Esto no es una lista de errores.** Son piezas que se meten en un volumen reservado que esta dibujado a partir de un numero que se ha inventado este repositorio: el radio minimo de curvatura de la fibra, el del coaxial y el diametro de haz siguen siendo **TBD**. Lo que dicen estas filas es *con la hipotesis de hoy, aqui no cabe*, y la manera de resolverlas NO es bajar el radio supuesto hasta que desaparezcan: es conseguir el dato. Por eso no tumban el codigo de salida.

Lo que estas filas estan diciendo, en una frase: **la cadena de fibra, tal y como esta repartida, no respeta un radio de curvatura de 30 mm**. Todas salen del mismo dato que falta, y ninguna es un error del reparto.

| tipo | pieza | keep-out | volumen cm3 | detalle |
|---|---|---|---|---|
| keep_out | laser_beacon_bajada | keepout_fibra_laser_dfb_1550_salida | 3.93 | laser_beacon_bajada invade el keep-out 'fibra_laser_dfb_1550_salida' (fibra) en 3.93 cm3, con el keep-out dibujado a partir de un valor SUPUESTO |
| keep_out | filtro_espectral | keepout_fibra_laser_dfb_1550_salida | 0.01 | filtro_espectral invade el keep-out 'fibra_laser_dfb_1550_salida' (fibra) en 0.01 cm3, con el keep-out dibujado a partir de un valor SUPUESTO |
| keep_out | laser_dfb_1550 | keepout_fibra_aislador_salida | 0.23 | laser_dfb_1550 invade el keep-out 'fibra_aislador_salida' (fibra) en 0.23 cm3, con el keep-out dibujado a partir de un valor SUPUESTO |
| keep_out | laser_beacon_bajada | keepout_fibra_aislador_salida | 1.42 | laser_beacon_bajada invade el keep-out 'fibra_aislador_salida' (fibra) en 1.42 cm3, con el keep-out dibujado a partir de un valor SUPUESTO |
| keep_out | filtro_espectral | keepout_fibra_aislador_salida | 0.23 | filtro_espectral invade el keep-out 'fibra_aislador_salida' (fibra) en 0.23 cm3, con el keep-out dibujado a partir de un valor SUPUESTO |
| keep_out | laser_dfb_1550 | keepout_fibra_filtro_espectral_entrada | 1.72 | laser_dfb_1550 invade el keep-out 'fibra_filtro_espectral_entrada' (fibra) en 1.72 cm3, con el keep-out dibujado a partir de un valor SUPUESTO |
| keep_out | aislador | keepout_fibra_filtro_espectral_entrada | 0.23 | aislador invade el keep-out 'fibra_filtro_espectral_entrada' (fibra) en 0.23 cm3, con el keep-out dibujado a partir de un valor SUPUESTO |
| keep_out | mod_fase_mpz_ln_10 | keepout_fibra_mod_intensidad_mxer_ln_10_entrada | 5.04 | mod_fase_mpz_ln_10 invade el keep-out 'fibra_mod_intensidad_mxer_ln_10_entrada' (fibra) en 5.04 cm3, con el keep-out dibujado a partir de un valor SUPUESTO |
| keep_out | mod_fase_mpz_ln_10 | keepout_fibra_acoplador_monitor_entrada | 0.73 | mod_fase_mpz_ln_10 invade el keep-out 'fibra_acoplador_monitor_entrada' (fibra) en 0.73 cm3, con el keep-out dibujado a partir de un valor SUPUESTO |
| keep_out | voa | keepout_fibra_acoplador_monitor_entrada | 0.53 | voa invade el keep-out 'fibra_acoplador_monitor_entrada' (fibra) en 0.53 cm3, con el keep-out dibujado a partir de un valor SUPUESTO |
| keep_out | mod_fase_mpz_ln_10 | keepout_fibra_voa_entrada | 2.65 | mod_fase_mpz_ln_10 invade el keep-out 'fibra_voa_entrada' (fibra) en 2.65 cm3, con el keep-out dibujado a partir de un valor SUPUESTO |
| keep_out | colimador | keepout_fibra_voa_salida | 0.30 | colimador invade el keep-out 'fibra_voa_salida' (fibra) en 0.30 cm3, con el keep-out dibujado a partir de un valor SUPUESTO |
| keep_out | acoplador_monitor | keepout_fibra_voa_salida | 5.04 | acoplador_monitor invade el keep-out 'fibra_voa_salida' (fibra) en 5.04 cm3, con el keep-out dibujado a partir de un valor SUPUESTO |

## Los keep-outs que hay (24)

| id | tipo | estado | dims mm | en que se basa |
|---|---|---|---|---|
| fibra_laser_dfb_1550_salida | fibra | supuesto | 50 x 60 x 58 | Tramo recto de 20 mm (integracion.fibra.longitud_boot_modelada) mas el envolvente de un codo de 30 mm (integracion.fibra.radio_curvatura_modelado). Lo |
| fibra_aislador_entrada | fibra | supuesto | 6 x 60 x 49 | Tramo recto de 20 mm (integracion.fibra.longitud_boot_modelada) mas el envolvente de un codo de 30 mm (integracion.fibra.radio_curvatura_modelado). Lo |
| fibra_aislador_salida | fibra | supuesto | 50 x 60 x 49 | Tramo recto de 20 mm (integracion.fibra.longitud_boot_modelada) mas el envolvente de un codo de 30 mm (integracion.fibra.radio_curvatura_modelado). Lo |
| fibra_filtro_espectral_entrada | fibra | supuesto | 50 x 60 x 49 | Tramo recto de 20 mm (integracion.fibra.longitud_boot_modelada) mas el envolvente de un codo de 30 mm (integracion.fibra.radio_curvatura_modelado). Lo |
| fibra_filtro_espectral_salida | fibra | supuesto | 6 x 60 x 49 | Tramo recto de 20 mm (integracion.fibra.longitud_boot_modelada) mas el envolvente de un codo de 30 mm (integracion.fibra.radio_curvatura_modelado). Lo |
| fibra_mod_intensidad_mxer_ln_10_entrada | fibra | supuesto | 13 x 55 x 50 | Tramo recto de 20 mm (integracion.fibra.longitud_boot_modelada) mas el envolvente de un codo de 30 mm (integracion.fibra.radio_curvatura_modelado). Lo |
| fibra_acoplador_monitor_entrada | fibra | supuesto | 13 x 42 x 50 | Tramo recto de 20 mm (integracion.fibra.longitud_boot_modelada) mas el envolvente de un codo de 30 mm (integracion.fibra.radio_curvatura_modelado). Lo |
| fibra_voa_entrada | fibra | supuesto | 13 x 49 x 50 | Tramo recto de 20 mm (integracion.fibra.longitud_boot_modelada) mas el envolvente de un codo de 30 mm (integracion.fibra.radio_curvatura_modelado). Lo |
| fibra_voa_salida | fibra | supuesto | 13 x 49 x 50 | Tramo recto de 20 mm (integracion.fibra.longitud_boot_modelada) mas el envolvente de un codo de 30 mm (integracion.fibra.radio_curvatura_modelado). Lo |
| fibra_mod_fase_mpz_ln_10_entrada | fibra | supuesto | 15 x 60 x 9 | Tramo recto de 20 mm (integracion.fibra.longitud_boot_modelada) mas el envolvente de un codo de 30 mm (integracion.fibra.radio_curvatura_modelado). Lo |
| fibra_laser_beacon_bajada_salida | fibra | supuesto | 6 x 60 x 58 | Tramo recto de 20 mm (integracion.fibra.longitud_boot_modelada) mas el envolvente de un codo de 30 mm (integracion.fibra.radio_curvatura_modelado). Lo |
| fibra_colimador_beacon_bajada_entrada | fibra | supuesto | 60 x 2 x 55 | Tramo recto de 20 mm (integracion.fibra.longitud_boot_modelada) mas el envolvente de un codo de 30 mm (integracion.fibra.radio_curvatura_modelado). Lo |
| coaxial_mod_intensidad_mxer_ln_10 | coaxial | supuesto | 26 x 7 x 50 | Envolvente de un codo de 25 mm a la salida del conector RF (integracion.coaxial.radio_curvatura_modelado, SUPUESTO). El conector SI es dato: 6.1 x 10  |
| coaxial_mod_fase_mpz_ln_10 | coaxial | supuesto | 26 x 25 x 50 | Envolvente de un codo de 25 mm a la salida del conector RF (integracion.coaxial.radio_curvatura_modelado, SUPUESTO). El conector SI es dato: 6.1 x 10  |
| haz_e02 | haz_libre | supuesto | 18 x 7 x 7 | Tubo de 7 mm de lado (integracion.optica.diametro_haz_modelado, SUPUESTO) en el hueco que queda entre las dos piezas. El diametro de haz de cada tramo |
| haz_e03 | haz_libre | supuesto | 5 x 7 x 7 | Tubo de 7 mm de lado (integracion.optica.diametro_haz_modelado, SUPUESTO) en el hueco que queda entre las dos piezas. El diametro de haz de cada tramo |
| haz_e04 | haz_libre | supuesto | 7 x 7 x 16 | Tubo de 7 mm de lado (integracion.optica.diametro_haz_modelado, SUPUESTO) en el hueco que queda entre las dos piezas. El diametro de haz de cada tramo |
| haz_e06 | haz_libre | supuesto | 7 x 5 x 7 | Tubo de 7 mm de lado (integracion.optica.diametro_haz_modelado, SUPUESTO) en el hueco que queda entre las dos piezas. El diametro de haz de cada tramo |
| haz_e07 | haz_libre | supuesto | 5 x 7 x 7 | Tubo de 7 mm de lado (integracion.optica.diametro_haz_modelado, SUPUESTO) en el hueco que queda entre las dos piezas. El diametro de haz de cada tramo |
| haz_e08 | haz_libre | supuesto | 7 x 5 x 7 | Tubo de 7 mm de lado (integracion.optica.diametro_haz_modelado, SUPUESTO) en el hueco que queda entre las dos piezas. El diametro de haz de cada tramo |
| haz_e10 | haz_libre | supuesto | 7 x 5 x 7 | Tubo de 7 mm de lado (integracion.optica.diametro_haz_modelado, SUPUESTO) en el hueco que queda entre las dos piezas. El diametro de haz de cada tramo |
| haz_e11 | haz_libre | supuesto | 5 x 7 x 7 | Tubo de 7 mm de lado (integracion.optica.diametro_haz_modelado, SUPUESTO) en el hueco que queda entre las dos piezas. El diametro de haz de cada tramo |
| haz_telescopio_colimado | haz_libre | supuesto | 90 x 90 x 213 | Envolvente del haz dentro del barrilete, derivada de 'optica' en data/components.yaml. SUPUESTO por partida doble: la apertura libre es una decision d |
| haz_telescopio_comprimido | haz_libre | supuesto | 7 x 7 x 198 | Envolvente del haz dentro del barrilete, derivada de 'optica' en data/components.yaml. SUPUESTO por partida doble: la apertura libre es una decision d |

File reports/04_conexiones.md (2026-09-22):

# Conexiones

Generado automaticamente el 2026-09-21 por `clau3d informe`.
No editar a mano: los numeros salen de `data/components.yaml`.

- Mision: CLAU - CubeSat Laser per a Aplicacions Ultrasegures
- Norma: CubeSat Design Specification Rev. 14.1, The CubeSat Program, Cal Poly SLO
- Estado del layout: **confirmada** (31 piezas colocadas)

Resumen: **16** no comprobable, **26** ok

| id | familia | desde | hasta | tipo | estado | recorrido mm | detalle |
|---|---|---|---|---|---|---|---|
| f01 | opticas_fibra | laser_dfb_1550 | aislador | fibra_pm | ok | 32 | Extremos colocados y holgura declarada, recorrido 32 mm |
| f02 | opticas_fibra | aislador | filtro_espectral | fibra_pm | ok | 72 | Extremos colocados y holgura declarada, recorrido 72 mm |
| f03 | opticas_fibra | filtro_espectral | mod_intensidad_mxer_ln_10 | fibra_pm | ok | 141 | Extremos colocados y holgura declarada, recorrido 141 mm |
| f04 | opticas_fibra | mod_intensidad_mxer_ln_10 | acoplador_monitor | fibra_pm | ok | 73 | Extremos colocados y holgura declarada, recorrido 73 mm |
| f05 | opticas_fibra | acoplador_monitor | voa | fibra_pm | ok | 56 | Extremos colocados y holgura declarada, recorrido 56 mm |
| f06 | opticas_fibra | voa | mod_fase_mpz_ln_10 | fibra_pm | ok | 71 | Extremos colocados y holgura declarada, recorrido 71 mm |
| f07 | opticas_fibra | mod_fase_mpz_ln_10 | colimador | fibra_pm | ok | 139 | Extremos colocados y holgura declarada, recorrido 139 mm |
| f08 | opticas_fibra | laser_beacon_bajada | colimador_beacon_bajada | fibra_sm | ok | 113 | Extremos colocados y holgura declarada, recorrido 113 mm |
| e01 | opticas_espacio_libre | colimador | espejo_plegado_cuantico | haz_libre | no comprobable | 42 | Extremos colocados, pero sin holgura de conector declarada: no se puede afirmar que quepa. |
| e02 | opticas_espacio_libre | espejo_plegado_cuantico | dicroico_d1 | haz_libre | no comprobable | 34 | Extremos colocados, pero sin holgura de conector declarada: no se puede afirmar que quepa. |
| e03 | opticas_espacio_libre | dicroico_d1 | fsm | haz_libre | no comprobable | 25 | Extremos colocados, pero sin holgura de conector declarada: no se puede afirmar que quepa. |
| e04 | opticas_espacio_libre | fsm | telescopio_cassegrain | haz_libre | no comprobable | 141 | Extremos colocados, pero sin holgura de conector declarada: no se puede afirmar que quepa. |
| e05 | opticas_espacio_libre | telescopio_cassegrain | EXTERIOR | apertura | ok | - | Extremos colocados y holgura declarada |
| e06 | opticas_espacio_libre | dicroico_d1 | dicroico_d2 | haz_libre | no comprobable | 21 | Extremos colocados, pero sin holgura de conector declarada: no se puede afirmar que quepa. |
| e07 | opticas_espacio_libre | dicroico_d2 | camara_beacon | haz_libre | no comprobable | 28 | Extremos colocados, pero sin holgura de conector declarada: no se puede afirmar que quepa. |
| e08 | opticas_espacio_libre | colimador_beacon_bajada | dicroico_d2 | haz_libre | no comprobable | 19 | Extremos colocados, pero sin holgura de conector declarada: no se puede afirmar que quepa. |
| e09 | opticas_espacio_libre | dicroico_d2 | dicroico_d1 | haz_libre | no comprobable | 21 | Extremos colocados, pero sin holgura de conector declarada: no se puede afirmar que quepa. |
| e10 | opticas_espacio_libre | dicroico_d1 | trampa_luz_d1 | haz_libre | no comprobable | 20 | Extremos colocados, pero sin holgura de conector declarada: no se puede afirmar que quepa. |
| e11 | opticas_espacio_libre | dicroico_d2 | fotodiodo_monitor_beacon | haz_libre | no comprobable | 19 | Extremos colocados, pero sin holgura de conector declarada: no se puede afirmar que quepa. |
| r01 | rf_coaxial | pcb2_drivers_opticos | laser_dfb_1550 | coaxial | no comprobable | 154 | Extremos colocados, pero sin holgura de conector declarada: no se puede afirmar que quepa. |
| r02 | rf_coaxial | pcb2_drivers_opticos | mod_intensidad_mxer_ln_10 | coaxial | no comprobable | 167 | Extremos colocados, pero sin holgura de conector declarada: no se puede afirmar que quepa. |
| r03 | rf_coaxial | pcb2_drivers_opticos | mod_fase_mpz_ln_10 | coaxial | no comprobable | 205 | Extremos colocados, pero sin holgura de conector declarada: no se puede afirmar que quepa. |
| d01 | datos | obc_kryten_m3_plus | pcb1_control_qkd | bus_datos | ok | 99 | Extremos colocados y holgura declarada, recorrido 99 mm |
| d02 | datos | obc_kryten_m3_plus | radio_banda_s_quasar_strx | bus_datos | ok | 61 | Extremos colocados y holgura declarada, recorrido 61 mm |
| d03 | datos | obc_kryten_m3_plus | pcb1_control_qkd | pps | ok | 99 | Extremos colocados y holgura declarada, recorrido 99 mm |
| d04 | datos | pcb1_control_qkd | pcb2_drivers_opticos | bus_datos | ok | 15 | Extremos colocados y holgura declarada, recorrido 15 mm |
| d05 | datos | pcb1_control_qkd | pcb3_pat | bus_datos | ok | 15 | Extremos colocados y holgura declarada, recorrido 15 mm |
| d06 | datos | adcs_iadcs400 | pcb3_pat | bus_datos | ok | 137 | Extremos colocados y holgura declarada, recorrido 137 mm |
| m01 | datos | acoplador_monitor | pcb2_drivers_opticos | senal_fotodiodo | ok | 163 | Extremos colocados y holgura declarada, recorrido 163 mm |
| m02 | datos | acoplador_monitor | pcb2_drivers_opticos | senal_fotodiodo | ok | 163 | Extremos colocados y holgura declarada, recorrido 163 mm |
| p01 | potencia | bateria_optimus_30 | eps_starbuck_nano_plus | potencia | ok | 114 | Extremos colocados y holgura declarada, recorrido 114 mm |
| p02 | potencia | paneles_photon_side | eps_starbuck_nano_plus | potencia | ok | 99 | Extremos colocados y holgura declarada, recorrido 99 mm |
| p03 | potencia | eps_starbuck_nano_plus | obc_kryten_m3_plus | potencia | ok | 30 | Extremos colocados y holgura declarada, recorrido 30 mm |
| p04 | potencia | eps_starbuck_nano_plus | adcs_iadcs400 | potencia | ok | 84 | Extremos colocados y holgura declarada, recorrido 84 mm |
| p05 | potencia | eps_starbuck_nano_plus | radio_banda_s_quasar_strx | potencia | ok | 30 | Extremos colocados y holgura declarada, recorrido 30 mm |
| p06 | potencia | eps_starbuck_nano_plus | pcb1_control_qkd | potencia | ok | 69 | Extremos colocados y holgura declarada, recorrido 69 mm |
| p07 | potencia | eps_starbuck_nano_plus | pcb2_drivers_opticos | potencia | ok | 84 | Extremos colocados y holgura declarada, recorrido 84 mm |
| p08 | potencia | eps_starbuck_nano_plus | pcb3_pat | potencia | ok | 53 | Extremos colocados y holgura declarada, recorrido 53 mm |
| p09 | potencia | eps_starbuck_nano_plus | laser_dfb_1550 | potencia | ok | 228 | Extremos colocados y holgura declarada, recorrido 228 mm |
| t01 | termico | bandeja_optica | pcb2_drivers_opticos | termico | no comprobable | - | Zona termica declarada pero sin ubicacion de sensores ni calefactores. |
| t03 | termico | franja_lateral | pcb2_drivers_opticos | termico | no comprobable | - | Zona termica declarada pero sin ubicacion de sensores ni calefactores. |
| t02 | termico | baterias | eps_starbuck_nano_plus | termico | no comprobable | - | Zona termica declarada pero sin ubicacion de sensores ni calefactores. |

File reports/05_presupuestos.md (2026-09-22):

# Presupuestos de masa y potencia

Generado automaticamente el 2026-09-21 por `clau3d informe`.
No editar a mano: los numeros salen de `data/components.yaml`.

- Mision: CLAU - CubeSat Laser per a Aplicacions Ultrasegures
- Norma: CubeSat Design Specification Rev. 14.1, The CubeSat Program, Cal Poly SLO
- Estado del layout: **confirmada** (31 piezas colocadas)

## Masa (g)

| estado del dato | total g |
|---|---|
| confirmado | 745.90 |
| referencia | 100.00 |
| **contabilizado** | **845.90** |

Limite de la norma: **12000 g**. Margen sobre lo contabilizado: **11154 g**.

> **Incompleto.** Sin dato (30): `estructura_6u`, `adcs_iadcs400`, `antena_quasar_wsant`, `radio_uhf_pulsar_vutrx`, `paneles_photon_side`, `propulsion`, `telescopio_cassegrain`, `fsm`, `dicroico_d1`, `dicroico_d2`, `camara_beacon`, `laser_beacon_bajada`, `colimador_beacon_bajada`, `fotodiodo_monitor_beacon`, `trampa_luz_d1`, `espejo_plegado_cuantico`, `colimador`, `bandeja_optica`, `laser_dfb_1550`, `mod_intensidad_mxer_ln_10`, `mod_fase_mpz_ln_10`, `voa`, `aislador`, `filtro_espectral`, `acoplador_monitor`, `pcb1_control_qkd`, `pcb2_drivers_opticos`, `pcb3_pat`, `cables_rf_moduladores`, `qrng_idq20mc1_s3`. El total real sera mayor; no se rellena ningun hueco.

| id | componente | subsistema | uds | unitario g | total g | estado | fuente |
|---|---|---|---|---|---|---|---|
| bateria_optimus_30 | AAC Clyde Space Optimus-30 (bateria) | EPS | 2 | 268.00 | 536.00 | confirmado | https://www.aac-clyde.space/wp-content/uploads/2021/11/AAC_DataSheet_Optimus.pdf |
| eps_starbuck_nano_plus | AAC Clyde Space Starbuck-Nano-PLUS (EPS) | EPS | 1 | 148.00 | 148.00 | confirmado | https://www.aac-clyde.space/wp-content/uploads/2021/11/AAC_DataSheet_Starbuck-Na |
| radio_banda_s_quasar_strx | AAC Clyde Space Quasar-STRX (transceptor banda S) | comunicaciones | 1 | 100.00 | 100.00 | referencia | Ficha AAC Pulsar-STX (via brief ACSAR 2026-09-19) |
| obc_kryten_m3_plus | AAC Clyde Space Kryten-M3-PLUS (OBC con GNSS) | OBC | 1 | 61.90 | 61.90 | confirmado | https://www.aac-clyde.space/wp-content/uploads/2021/10/AAC_DataSheet_Kryten.pdf |

## Potencia nominal (W)

| estado del dato | total W |
|---|---|
| confirmado | 6.83 |
| **contabilizado** | **6.83** |

> **Incompleto.** Sin dato (22): `telescopio_cassegrain`, `fsm`, `dicroico_d1`, `dicroico_d2`, `camara_beacon`, `laser_beacon_bajada`, `colimador_beacon_bajada`, `fotodiodo_monitor_beacon`, `trampa_luz_d1`, `espejo_plegado_cuantico`, `colimador`, `bandeja_optica`, `mod_intensidad_mxer_ln_10`, `mod_fase_mpz_ln_10`, `voa`, `aislador`, `filtro_espectral`, `acoplador_monitor`, `pcb1_control_qkd`, `pcb2_drivers_opticos`, `pcb3_pat`, `cables_rf_moduladores`. El total real sera mayor; no se rellena ningun hueco.

| id | componente | subsistema | uds | unitario W | total W | estado | fuente |
|---|---|---|---|---|---|---|---|
| laser_dfb_1550 | Laser DFB 1550 nm, Gooch & Housego (modulo validado para espacio) | bandeja_optica | 1 | 4.10 | 4.10 | confirmado | Brief ACSAR 2026-09-19 (cita ficha Gooch & Housego) |
| adcs_iadcs400 | AAC Clyde Space iADCS400 | ADCS | 1 | 2.00 | 2.00 | confirmado | Brief ACSAR 2026-09-19 (cita ficha AAC Clyde Space) |
| obc_kryten_m3_plus | AAC Clyde Space Kryten-M3-PLUS (OBC con GNSS) | OBC | 1 | 0.40 | 0.40 | confirmado | https://www.aac-clyde.space/wp-content/uploads/2021/10/AAC_DataSheet_Kryten.pdf |
| qrng_idq20mc1_s3 | QRNG ID Quantique IDQ20MC1-S3 | control_qkd | 4 | 0.08 | 0.33 | confirmado | Brief ACSAR 2026-09-19 (cita ficha ID Quantique) |

## Potencia de pico (W)

| estado del dato | total W |
|---|---|
| confirmado | 5.00 |
| referencia | 5.00 |
| **contabilizado** | **10.00** |

> **Incompleto.** Sin dato (24): `telescopio_cassegrain`, `fsm`, `dicroico_d1`, `dicroico_d2`, `camara_beacon`, `laser_beacon_bajada`, `colimador_beacon_bajada`, `fotodiodo_monitor_beacon`, `trampa_luz_d1`, `espejo_plegado_cuantico`, `colimador`, `bandeja_optica`, `laser_dfb_1550`, `mod_intensidad_mxer_ln_10`, `mod_fase_mpz_ln_10`, `voa`, `aislador`, `filtro_espectral`, `acoplador_monitor`, `pcb1_control_qkd`, `pcb2_drivers_opticos`, `pcb3_pat`, `cables_rf_moduladores`, `qrng_idq20mc1_s3`. El total real sera mayor; no se rellena ningun hueco.

| id | componente | subsistema | uds | unitario W | total W | estado | fuente |
|---|---|---|---|---|---|---|---|
| radio_banda_s_quasar_strx | AAC Clyde Space Quasar-STRX (transceptor banda S) | comunicaciones | 1 | 5.00 | 5.00 | referencia | Ficha AAC Pulsar-STX (via brief ACSAR 2026-09-19) |
| adcs_iadcs400 | AAC Clyde Space iADCS400 | ADCS | 1 | 4.00 | 4.00 | confirmado | Web AAC Clyde Space (via brief ACSAR 2026-09-19) |
| obc_kryten_m3_plus | AAC Clyde Space Kryten-M3-PLUS (OBC con GNSS) | OBC | 1 | 1.00 | 1.00 | confirmado | https://www.aac-clyde.space/wp-content/uploads/2021/10/AAC_DataSheet_Kryten.pdf |

## Energia almacenada

- Modulos modelados: **2** (estado de la cantidad real: **TBD**)
- Capacidad por modulo: 30.0 Wh
- Total modelado: 60.0 Wh

> El numero de modulos es una hipotesis de trabajo para reservar volumen, no una decision cerrada.

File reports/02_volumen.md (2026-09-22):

# Informe de volumen

Generado automaticamente el 2026-09-21 por `clau3d informe`.
No editar a mano: los numeros salen de `data/components.yaml`.

- Mision: CLAU - CubeSat Laser per a Aplicacions Ultrasegures
- Norma: CubeSat Design Specification Rev. 14.1, The CubeSat Program, Cal Poly SLO
- Estado del layout: **confirmada** (31 piezas colocadas)

> **Unidades.** Los volumenes van en **cm3** y en **litros**; las longitudes, en **mm**. La **U** de la CDS es un *formato* (una ranura de dispensador de 100 x 100 x 113.5 mm), no una unidad de volumen, asi que aqui no se usa para medir hueco libre: decir que la envolvente 6U "mide 8.28 U" mezcla las dos cosas. Cuando aparece "6U" se refiere al formato de la envolvente exterior (226.3 x 100 x 366 mm), nunca a un volumen calculado.

## Resumen

| Concepto | cm3 | L |
|---|---|---|
| Envolvente exterior (formato 6U) | 8282.6 | 8.28 |
| Zona util interior | 7643.7 | 7.64 |
| Ocupado por piezas colocadas | 4989.1 | 4.99 |
| Ocupado segun catalogo (con o sin colocar) | 4531.2 | 4.53 |
| Libre dentro de la zona util | 2654.6 | 2.65 |

> **El volumen libre de arriba NO es el volumen libre real.**

> Sin envolvente conocida (3): `radio_uhf_pulsar_vutrx`, `propulsion`, `cables_rf_moduladores`.

> Sin colocar (3): `radio_uhf_pulsar_vutrx`, `propulsion`, `cables_rf_moduladores`.

## Por componente

`fuente` dice de donde sale el solido que se dibuja; `estado` de donde salen sus cotas. No siempre coinciden: una pieza con ficha confirmada y STEP de referencia se dibuja como referencia, porque lo que se esta viendo es el STEP. `envolvente` es la caja que ocupa YA GIRADA Y COLOCADA, conectores incluidos, que es lo que ve el detector de interferencias.

| id drive | id | componente | fuente | estado | uds | volumen cm3 | envolvente mm | keep-outs | centro mm | colocado |
|---|---|---|---|---|---|---|---|---|---|---|
| OPT-13 | telescopio_cassegrain | Telescopio Cassegrain on-axis, apertura 90 mm | aproximado propio: cassegrain (esperando STEP) | supuesto | 1 | 2066.0 | 95 x 95 x 227 | 0 | (37, 0, 67) | si |
| PLAT-04 | adcs_iadcs400 | AAC Clyde Space iADCS400 | aproximado propio: caja | confirmado | 1 | 615.7 | 96 x 95 x 67 | 0 | (-61, 0, 143) | si |
| PLAT-07 | paneles_photon_side | AAC Clyde Space PHOTON-SIDE (paneles de montaje en cuerpo) | aproximado propio: caja | supuesto | 2 | 511.3 | 209 x 4 x 349 | 0 | (0, 52, 0) | si |
| PLAT-06 | bateria_optimus_30 | AAC Clyde Space Optimus-30 (bateria) | STEP de fabricante | referencia | 2 | 372.7 | 96 x 90 x 36 | 0 | (-61, 0, -56) | si |
| PLAT-05 | eps_starbuck_nano_plus | AAC Clyde Space Starbuck-Nano-PLUS (EPS) | aproximado propio: caja | confirmado | 1 | 180.0 | 96 x 90 x 21 | 0 | (-61, 0, 59) | si |
| PLAT-02 | radio_banda_s_quasar_strx | AAC Clyde Space Quasar-STRX (transceptor banda S) | aproximado propio: caja | referencia | 1 | 146.0 | 96 x 90 x 17 | 0 | (-61, 0, 28) | si |
| ELEC-01 | pcb1_control_qkd | PCB-1 Control QKD (FPGA, QRNG, memoria, reloj) | aproximado propio: caja | supuesto | 1 | 129.7 | 96 x 90 x 15 | 0 | (-61, 0, -10) | si |
| ELEC-02 | pcb2_drivers_opticos | PCB-2 Drivers opticos | aproximado propio: caja | supuesto | 1 | 129.7 | 96 x 90 x 15 | 0 | (-61, 0, -25) | si |
| ELEC-03 | pcb3_pat | PCB-3 PAT (apuntado, adquisicion y seguimiento) | aproximado propio: caja | supuesto | 1 | 129.7 | 96 x 90 x 15 | 0 | (-61, 0, 5) | si |
| PLAT-03 | antena_quasar_wsant | AAC Clyde Space Quasar-WSANT (antena banda S) | aproximado propio: caja | supuesto | 1 | 67.2 | 82 x 82 x 10 | 0 | (-61, 0, -176) | si |
| PLAT-01 | obc_kryten_m3_plus | AAC Clyde Space Kryten-M3-PLUS (OBC con GNSS) | STEP de fabricante | referencia | 1 | 47.6 | 96 x 90 x 23 | 0 | (-61, 0, 89) | si |
| OPT-14 | bandeja_optica | Bandeja optica (placa mecanica, no PCB) | aproximado propio: caja | supuesto | 1 | 26.6 | 118 x 3 x 75 | 0 | (50, -46, -141) | si |
| OPT-11 | camara_beacon | Camara / sensor de beacon de subida (medida del error de apuntado) | aproximado propio: caja | supuesto | 1 | 20.3 | 30 x 26 x 26 | 0 | (33, 21, -74) | si |
| OPT-03 | mod_fase_mpz_ln_10 | Exail MPZ-LN-10 (modulador de fase, codificador de polarizacion) | aproximado propio: caja | referencia | 1 | 16.0 | 10 x 25 x 130 | 2 | (96, 5, 107) | si |
| OPT-02 | mod_intensidad_mxer_ln_10 | Exail MXER-LN-10 (modulador de intensidad, grado espacial EM/NS-FM/FM) | aproximado propio: caja | confirmado | 1 | 16.0 | 10 x 25 x 130 | 2 | (98, -28, 19) | si |
| OPT-07 | acoplador_monitor | Acoplador 2x2 de monitorizacion + dos fotodiodos | aproximado propio: caja | supuesto | 1 | 14.4 | 12 x 20 x 60 | 1 | (98, 36, -16) | si |
| OPT-12 | laser_beacon_bajada | Modulo laser de beacon de bajada (1064 nm), fiberizado | aproximado propio: caja | supuesto | 1 | 12.0 | 40 x 15 x 20 | 1 | (85, -37, -153) | si |
| OPT-09 | dicroico_d1 | Dicroico D1 (separacion canal cuantico / beacons) | aproximado propio: caja | supuesto | 1 | 4.1 | 16 x 16 x 16 | 0 | (61, 0, -74) | si |
| OPT-15 | dicroico_d2 | Dicroico D2 (separacion beacon de subida / beacon de bajada) | aproximado propio: caja | supuesto | 1 | 4.1 | 16 x 16 x 16 | 0 | (61, 21, -74) | si |
| OPT-19 | espejo_plegado_cuantico | Espejo de plegado del canal cuantico (plano metalico a 45 grados) | aproximado propio: caja | supuesto | 1 | 4.1 | 16 x 16 x 16 | 0 | (96, 0, -74) | si |
| OPT-08 | colimador | Colimador fibra a espacio libre | aproximado propio: cilindro | supuesto | 1 | 4.0 | 12 x 12 x 28 | 1 | (96, 0, -32) | si |
| OPT-01 | laser_dfb_1550 | Laser DFB 1550 nm, Gooch & Housego (modulo validado para espacio) | aproximado propio: caja | referencia | 1 | 3.7 | 37 x 8 x 43 | 1 | (14, -41, -153) | si |
| OPT-17 | trampa_luz_d1 | Trampa de luz del cuarto puerto de D1 | aproximado propio: caja | supuesto | 1 | 3.4 | 15 x 15 x 15 | 0 | (61, -20, -74) | si |
| OPT-16 | fotodiodo_monitor_beacon | Fotodiodo de monitorizacion de potencia del beacon de bajada | aproximado propio: caja | supuesto | 1 | 1.7 | 12 x 12 x 12 | 0 | (80, 21, -74) | si |
| OPT-06 | filtro_espectral | Filtro espectral | aproximado propio: cilindro | supuesto | 1 | 1.2 | 40 x 6 x 6 | 2 | (85, -42, -121) | si |
| OPT-05 | aislador | Aislador optico | aproximado propio: cilindro | supuesto | 1 | 1.1 | 35 x 6 x 6 | 2 | (13, -42, -121) | si |
| OPT-04 | voa | Atenuador optico variable (VOA) | aproximado propio: cilindro | supuesto | 1 | 1.1 | 6 x 6 x 35 | 2 | (98, 28, 39) | si |
| OPT-10 | fsm | Espejo de apuntado fino (FSM) - opcion MEMS | aproximado propio: caja | referencia | 1 | 1.0 | 23 x 15 x 23 | 0 | (37, 0, -74) | si |
| OPT-20 | colimador_beacon_bajada | Colimador de fibra del beacon de bajada (1064 nm) | aproximado propio: cilindro | supuesto | 1 | 0.8 | 8 x 12 x 8 | 1 | (61, 40, -74) | si |
| ELEC-01.1 | qrng_idq20mc1_s3 | QRNG ID Quantique IDQ20MC1-S3 | aproximado propio: caja | confirmado | 4 | 0.1 | - | 0 | - | no |
| ELEC-04 | cables_rf_moduladores | Coaxiales RF de PCB-2 a los dos moduladores | sin geometria | TBD | 2 | - | - | 0 | - | no |
| - | propulsion | Modulo de propulsion (opcional) | sin geometria | TBD | 1 | - | - | 0 | - | no |
| - | radio_uhf_pulsar_vutrx | AAC Clyde Space Pulsar-VUTRX (UHF, TT&C de respaldo) | sin geometria | TBD | 1 | - | - | 0 | - | no |

## Hueco libre por columna

| columna | total cm3 | ocupado cm3 | libre cm3 | libre L | % ocupado |
|---|---|---|---|---|---|
| Plataforma (pila PC104) | 3447.8 | 2229.2 | 1218.5 | 1.22 | 65% |
| Payload (telescopio, franja, banco y bandeja) | 4195.9 | 2248.5 | 1947.4 | 1.95 | 54% |

> El **ocupado** son cajas envolventes, no volumen de material: un cilindro cuenta por su cilindro, pero una caja con un conector cuenta el hueco entero. Y el **libre** es un techo mientras quede un solo componente sin colocar o sin envolvente.

## Hueco libre por zona

| zona | nombre | total cm3 | ocupado cm3 | libre cm3 | libre L | % ocupado |
|---|---|---|---|---|---|---|
| z_plataforma | Columna de plataforma - pila PC104 a lo largo de todo Z | 3447.8 | 2229.2 | 1218.5 | 1.22 | 65% |
| z_payload_telescopio | Telescopio | 2066.0 | 2066.0 | 0.0 | 0.00 | 100% |
| z_payload_franja | Franja lateral - modulacion, monitorizacion, atenuacion y codificacion | 569.5 | 82.5 | 487.0 | 0.49 | 14% |
| z_payload_banco | Banco optico de espacio libre | 638.6 | 46.5 | 592.1 | 0.59 | 7% |
| z_payload_bandeja | Bandeja optica de fibra | 921.8 | 53.5 | 868.3 | 0.87 | 6% |

## Supuestos pendientes de sustituir (78)

Cada fila es un numero que este repositorio se ha inventado para poder dibujar algo. Ninguno suma en los presupuestos de masa ni de potencia, y todos se dibujan en gris. Sustituir cualquiera de ellos por una cifra con fuente es, literalmente, todo lo que hay que hacer para que esta parte del modelo deje de ser una reserva y pase a ser un dato.

| componente | magnitud | valor modelado | que falta | pedir a |
|---|---|---|---|---|
| integracion | integracion.fibra.radio_curvatura_modelado | `30.0` | Radio minimo de curvatura real, que es 'radio_minimo_curvatura' | Equipo de payload de ACSAR |
| integracion | integracion.fibra.longitud_protector_empalme | `60.0` | Protector de empalme elegido y su tramo recto real | Equipo de payload de ACSAR |
| integracion | integracion.fibra.tolerancia_coaxialidad | `0.5` | Tolerancia de alineacion del colimador elegido, y presupuesto de alineacion del montaje | Equipo de optica / de payload de ACSAR |
| integracion | integracion.fibra.longitud_boot_modelada | `20.0` | Tipo de conector o protector y su tramo recto de salida | Equipo de payload de ACSAR |
| integracion | integracion.bandeja.holgura_montaje | `2.0` | Holgura de montaje real de la placa contra el chasis, del patron de taladros | Equipo de estructura de ACSAR |
| integracion | integracion.coaxial.radio_curvatura_modelado | `25.0` | Radio minimo de curvatura del coaxial elegido. Es el mismo hueco que 'cables_rf_moduladores.radio_minimo_curvatura'. | Equipo de electronica de ACSAR |
| integracion | integracion.optica.diametro_haz_modelado | `7.0` | Diametro de haz de cada tramo (e01 a e05 en data/connections.yaml) y el semiangulo del cono de la apertura. SIGUE SIENDO TBD: lo de aqui es un techo geometrico, no una medida del diseno optico. | Equipo de optica de ACSAR |
| integracion | integracion.optica.apertura_libre_optica_banco | `11.4` | Apertura libre real de la montura elegida para D1, D2 y el espejo de plegado | Equipo de optica de ACSAR |
| integracion | integracion.optica.punto_de_adelanto | `50.7` | Punto de adelanto maximo del enlace, del analisis de mision (orbita y geometria de los pases) | Equipo de PAT / de mision de ACSAR |
| integracion | integracion.optica.potencia_beacon_bajada | `100.0` | Potencia optica de bajada del presupuesto de enlace (divergencia, distancia, sensibilidad del receptor de la estacion) | Equipo de PAT / de mision de ACSAR |
| integracion | integracion.optica.borde_dicroico_d1 | `1300.0` | Longitud de onda de corte, anchura de la transicion y curvas de transmision y reflexion del divisor elegido | Equipo de optica de ACSAR |
| integracion | integracion.optica.borde_dicroico_d2 | `1020.0` | Longitud de onda de corte, anchura de la transicion y curvas de transmision y reflexion del divisor elegido | Equipo de optica de ACSAR |
| antena_quasar_wsant | antena_quasar_wsant.dimensiones | `[82.0, 82.0, 10.0]` | Dimensiones reales, ganancia, diagrama de radiacion y cara de montaje | AAC Clyde Space |
| paneles_photon_side | paneles_photon_side.dimensiones | `[209.3, 3.5, 349.0]` | Contorno real de cada tamano de PHOTON-SIDE (1U/2U/3U/6U) y cual de ellos se monta en cada cara | AAC Clyde Space / Equipo de potencia de ACSAR |
| telescopio_cassegrain | telescopio_cassegrain.dimensiones | `[95.4, 95.4, 227.0]` | Diametro exterior del barrilete y longitud optica real. YA EXISTE un concepto en formato nativo SolidWorks (Telescopio_concepto.SLDPRT, entrega "Preliminar viability model" del 2026-09-20), ilegible. Hace falta reexportarlo a STEP AP214 o AP242 y dejarlo en la ruta de 'step_esperado'. Ver cad/vendor/MANIFEST.yaml, seccion 'sin_convertir'. | Oscar (ACSAR) / Aperture Optical Sciences |
| telescopio_cassegrain | telescopio_cassegrain.optica.focal_primario | `200.0` | Focal real del primario, del diseno optico de Aperture Optical Sciences | Oscar (ACSAR) / Aperture Optical Sciences |
| telescopio_cassegrain | telescopio_cassegrain.optica.conica_primario | `-1.0` | Constante conica real del primario del diseno optico | Oscar (ACSAR) / Aperture Optical Sciences |
| telescopio_cassegrain | telescopio_cassegrain.optica.conica_secundario | `-1.0` | Constante conica real del secundario del diseno optico | Oscar (ACSAR) / Aperture Optical Sciences |
| telescopio_cassegrain | telescopio_cassegrain.optica.distancia_focal_trasera | `40.0` | Distancia focal trasera del diseno focal, si se eligiera esa configuracion | Oscar (ACSAR) / Aperture Optical Sciences |
| telescopio_cassegrain | telescopio_cassegrain.optica.margen_secundario | `1.4` | Sobredimensionado real del secundario (campo de vista y alineacion) | Equipo de optica de ACSAR |
| telescopio_cassegrain | telescopio_cassegrain.optica.margen_agujero_primario | `4.0` | Diametro real del agujero central del primario | Oscar (ACSAR) / Aperture Optical Sciences |
| telescopio_cassegrain | telescopio_cassegrain.optica.margen_substrato_primario | `1.0` | Diametro exterior real del sustrato del primario | Oscar (ACSAR) / Aperture Optical Sciences |
| telescopio_cassegrain | telescopio_cassegrain.optica.seccion_barrilete | `[95.4, 95.4]` | Contorno exterior real del barrilete | Oscar (ACSAR) / Aperture Optical Sciences |
| telescopio_cassegrain | telescopio_cassegrain.optica.espesor_pared_barrilete | `1.5` | Espesor y material reales de la pared del barrilete | Equipo de estructura de ACSAR / Aperture Optical Sciences |
| telescopio_cassegrain | telescopio_cassegrain.optica.espesor_mamparo | `3.0` | Espesor real de los mamparos | Equipo de estructura de ACSAR / Aperture Optical Sciences |
| telescopio_cassegrain | telescopio_cassegrain.optica.lado_larguero_esquina | `12.0` | Seccion real de los largueros, del analisis de rigidez del tubo | Equipo de estructura de ACSAR |
| telescopio_cassegrain | telescopio_cassegrain.optica.brida_interfaz_fsm | `[40.0, 40.0]` | Interfaz mecanica real telescopio-banco (patron de taladros y plano de referencia) | Oscar (ACSAR) / Equipo de optica de ACSAR |
| telescopio_cassegrain | telescopio_cassegrain.optica.espesor_brida | `3.0` | Espesor real de la brida de interfaz | Oscar (ACSAR) / Equipo de optica de ACSAR |
| telescopio_cassegrain | telescopio_cassegrain.optica.margen_agujero_entrada | `2.0` | Diametro real del agujero de entrada | Oscar (ACSAR) / Aperture Optical Sciences |
| telescopio_cassegrain | telescopio_cassegrain.optica.espesor_espejo_primario | `8.0` | Espesor y material reales del sustrato del primario | Oscar (ACSAR) / Aperture Optical Sciences |
| telescopio_cassegrain | telescopio_cassegrain.optica.espesor_espejo_secundario | `4.0` | Espesor y material reales del sustrato del secundario | Oscar (ACSAR) / Aperture Optical Sciences |
| telescopio_cassegrain | telescopio_cassegrain.optica.altura_celda | `3.0` | Altura real de la celda isostatica del primario | Oscar (ACSAR) / Aperture Optical Sciences |
| telescopio_cassegrain | telescopio_cassegrain.optica.flexures | `3` | Numero y tipo reales de flexures de la celda | Oscar (ACSAR) / Aperture Optical Sciences |
| telescopio_cassegrain | telescopio_cassegrain.optica.radio_circulo_flexures | `40.0` | Radio real del circulo de apoyo de la celda | Oscar (ACSAR) / Aperture Optical Sciences |
| telescopio_cassegrain | telescopio_cassegrain.optica.angulo_primer_flexure | `45.0` | Orientacion real de la celda respecto al barrilete | Oscar (ACSAR) / Aperture Optical Sciences |
| telescopio_cassegrain | telescopio_cassegrain.optica.seccion_flexure | `[6.0, 6.0]` | Seccion real de los flexures | Oscar (ACSAR) / Aperture Optical Sciences |
| telescopio_cassegrain | telescopio_cassegrain.optica.margen_buje_secundario | `3.0` | Montura real del secundario | Oscar (ACSAR) / Aperture Optical Sciences |
| telescopio_cassegrain | telescopio_cassegrain.optica.tornillos_colimacion | `3` | Mecanismo real de colimacion del secundario | Oscar (ACSAR) / Aperture Optical Sciences |
| telescopio_cassegrain | telescopio_cassegrain.optica.diametro_tornillo_colimacion | `3.0` | Tornilleria real de colimacion | Oscar (ACSAR) / Aperture Optical Sciences |
| telescopio_cassegrain | telescopio_cassegrain.optica.vanes | `4` | Numero real de vanes de la arana | Oscar (ACSAR) / Aperture Optical Sciences |
| telescopio_cassegrain | telescopio_cassegrain.optica.espesor_vane | `0.8` | Espesor real de los vanes | Equipo de estructura de ACSAR / Aperture Optical Sciences |
| telescopio_cassegrain | telescopio_cassegrain.optica.ancho_vane | `6.0` | Geometria real de la arana | Oscar (ACSAR) / Aperture Optical Sciences |
| telescopio_cassegrain | telescopio_cassegrain.optica.holgura_baffle | `0.5` | Holgura real entre el haz y el baffle, del analisis de luz parasita | Equipo de optica de ACSAR |
| telescopio_cassegrain | telescopio_cassegrain.optica.espesor_baffle | `0.6` | Espesor real de los baffles | Equipo de optica de ACSAR |
| telescopio_cassegrain | telescopio_cassegrain.optica.diafragmas_internos | `4` | Numero y posicion reales de los diafragmas, del analisis de luz parasita | Equipo de optica de ACSAR |
| telescopio_cassegrain | telescopio_cassegrain.optica.espesor_diafragma | `1.0` | Espesor real de los diafragmas | Equipo de optica de ACSAR |
| telescopio_cassegrain | telescopio_cassegrain.optica.angulo_exclusion_solar_modelado | `30.0` | El angulo de verdad, que es 'angulo_exclusion_solar' | Equipo de optica de ACSAR |
| fsm_piezo_pi_s331 | fsm_piezo_pi_s331.dimensiones | `[50.0, 50.0, 22.0]` | Cotas exteriores del S-331 (plano acotado o STEP) | Physik Instrumente |
| dicroico_d1 | dicroico_d1.dimensiones | `[16.0, 16.0, 16.0]` | Divisor y montura elegidos, con su apertura libre, sus longitudes de onda de corte y la envolvente real del soporte | Equipo de optica de ACSAR |
| dicroico_d2 | dicroico_d2.dimensiones | `[16.0, 16.0, 16.0]` | Divisor y montura elegidos, con su apertura libre, su longitud de onda de corte y la envolvente real del soporte | Equipo de optica de ACSAR |
| camara_beacon | camara_beacon.dimensiones | `[30.0, 26.0, 26.0]` | Modelo de sensor, distancia focal del objetivo, campo de vision exigido por el lazo de apuntado y espesor del filtro de banda estrecha de 976 nm | Equipo de PAT de ACSAR |
| laser_beacon_bajada | laser_beacon_bajada.dimensiones | `[40.0, 20.0, 15.0]` | Modelo del modulo elegido, potencia optica real, consumo electrico y su interfaz termica contra la bandeja | Equipo de PAT de ACSAR |
| colimador_beacon_bajada | colimador_beacon_bajada.dimensiones | `[8.0, 12.0, 8.0]` | Colimador elegido, su envolvente real y el diametro de haz que entrega, que es lo que tiene que cuadrar con la apertura de D2 | Equipo de PAT / de optica de ACSAR |
| fotodiodo_monitor_beacon | fotodiodo_monitor_beacon.dimensiones | `[12.0, 12.0, 12.0]` | Modelo de fotodiodo, encapsulado y electronica de acondicionamiento | Equipo de PAT de ACSAR |
| trampa_luz_d1 | trampa_luz_d1.dimensiones | `[15.0, 15.0, 15.0]` | Tipo de absorbedor, su envolvente y el rechazo exigido | Equipo de optica de ACSAR |
| trampa_luz_d2 | trampa_luz_d2.dimensiones | `[15.0, 15.0, 15.0]` | Tipo de absorbedor, su envolvente y el rechazo exigido | Equipo de optica de ACSAR |
| espejo_plegado_cuantico | espejo_plegado_cuantico.dimensiones | `[16.0, 16.0, 16.0]` | Espejo y montura elegidos, con su apertura libre y la envolvente real del soporte | Equipo de optica de ACSAR |
| colimador | colimador.dimensiones | `[28.0, 12.0, 12.0]` | Diametro del haz colimado y modelo de colimador. Es el mismo dato que bloquea los keep-outs del camino optico. | Equipo de optica de ACSAR |
| bandeja_optica | bandeja_optica.dimensiones | `[117.7, 3.0, 75.4]` | Material, espesor y patron de taladros de la placa, del analisis estructural y termico | Equipo de estructura de ACSAR |
| laser_dfb_1550 | laser_dfb_1550.pines_btf14.dimensiones | `[30.0, 15.3, 4.0]` | Cotas de la fila de pines del modulo elegido | Gooch & Housego |
| laser_dfb_1550 | laser_dfb_1550.pines_btf14_b.dimensiones | `[30.0, 15.3, 4.0]` | Cotas de la fila de pines del modulo elegido | Gooch & Housego |
| mod_intensidad_mxer_ln_10 | mod_intensidad_mxer_ln_10.rf.dimensiones | `[6.1, 10.0, 6.1]` | Profundidad del conector RF, y holgura de insercion del coaxial | Exail / Equipo de electronica de ACSAR |
| mod_intensidad_mxer_ln_10 | mod_intensidad_mxer_ln_10.fibra_entrada.dimensiones | `[10.0, 3.0, 3.0]` | Diametro del protector de fibra del encapsulado de grado espacial | Exail |
| mod_intensidad_mxer_ln_10 | mod_intensidad_mxer_ln_10.fibra_salida.dimensiones | `[10.0, 3.0, 3.0]` | Diametro del protector de fibra del encapsulado de grado espacial | Exail |
| mod_fase_mpz_ln_10 | mod_fase_mpz_ln_10.rf.dimensiones | `[6.1, 10.0, 6.1]` | Profundidad del conector RF, y holgura de insercion del coaxial | Exail / Equipo de electronica de ACSAR |
| mod_fase_mpz_ln_10 | mod_fase_mpz_ln_10.fibra_entrada.dimensiones | `[10.0, 3.0, 3.0]` | Diametro del protector de fibra del encapsulado de grado espacial | Exail |
| mod_fase_mpz_ln_10 | mod_fase_mpz_ln_10.fibra_salida.dimensiones | `[10.0, 3.0, 3.0]` | Diametro del protector de fibra del encapsulado de grado espacial | Exail |
| voa | voa.dimensiones | `[35.0, 5.5, 5.5]` | Modelo de VOA elegido y su envolvente | Equipo de payload de ACSAR |
| atenuador_fijo | atenuador_fijo.dimensiones | `[25.0, 5.5, 5.5]` | Modelo de atenuador fijo elegido y su envolvente | Equipo de payload de ACSAR |
| aislador | aislador.dimensiones | `[35.0, 5.5, 5.5]` | Modelo de aislador elegido y su envolvente | Equipo de payload de ACSAR |
| aislador | aislador.aislamiento | `50.0` | Aislamiento del aislador elegido, medido a 1550 nm | Equipo de payload de ACSAR |
| filtro_espectral | filtro_espectral.dimensiones | `[40.0, 5.5, 5.5]` | Modelo de filtro elegido, su ancho de banda y su envolvente | Equipo de payload de ACSAR |
| filtro_espectral | filtro_espectral.ancho_banda | `0.8` | Ancho espectral real del pulso del DFB conmutado en ganancia, y ancho de banda del filtro elegido | Equipo de payload de ACSAR |
| acoplador_monitor | acoplador_monitor.dimensiones | `[60.0, 20.0, 12.0]` | Modelo de acoplador 2x2 y de los dos fotodiodos, y si van en la bandeja o montados en PCB-2 | Equipo de payload de ACSAR |
| acoplador_monitor | acoplador_monitor.razon_acoplamiento | `[99.0, 1.0]` | Razon de acoplamiento del acoplador elegido, y sensibilidad del fotodiodo, que es lo que la fija | Equipo de payload de ACSAR |
| pcb1_control_qkd | pcb1_control_qkd.dimensiones | `[95.89, 90.17, 15.0]` | Altura real de la tarjeta, que la fija el componente mas alto (la FPGA y su disipador, si lleva). Y confirmar el contorno PC104. | Equipo de electronica de ACSAR |
| pcb2_drivers_opticos | pcb2_drivers_opticos.dimensiones | `[95.89, 90.17, 15.0]` | Altura real de la tarjeta. Los drivers RF y el del Peltier son los candidatos a componente mas alto. Y confirmar el contorno PC104. | Equipo de electronica de ACSAR |
| pcb3_pat | pcb3_pat.dimensiones | `[95.89, 90.17, 15.0]` | Altura real de la tarjeta, y si el driver del FSM es de alta tension (un driver piezo de 120 V ocupa bastante mas que uno de MEMS). Es el mismo dato que bloquea la eleccion del FSM. Y confirmar el contorno. | Equipo de electronica de ACSAR |

## Mapa del hueco libre

Vista desde +Y (planta). Eje horizontal Z (-Z izquierda, +Z derecha),
eje vertical X (+X arriba). De ` ` (vacio) a `@` (lleno).

```
                                    
  ..      .  +++---...====::::::::: 
  ..                                
  ..         @@@@@@@@@@@@@@@@@@@@@@@
  ..      +  @@@@@@@@@@@@@@@@@@@@@@@
          +  @@@@@@@@@@@@@@@@@@@@@@@
         === @@@@@@@@@@@@@@@@@@@@@@@
         === @@@@@@@@@@@@@@@@@@@@@@@
         ::: @@@@@@@@@@@@@@@@@@@@@@@
             @@@@@@@@@@@@@@@@@@@@@@@
             @@@@@@@@@@@@@@@@@@@@@@@
             @@@@@@@@@@@@@@@@@@@@@@@
      @@@@ @@@ @@@@ @@ @@ @@ @@@@@@@
#     @@@@ @@@ @@@@ @@ @@ @@ @@@@@@@
#     @@@@ @@@ @@@@ @@ @@ @@ @@@@@@@
#     @@@@ @@@ @@@@ @@ @@ @@ @@@@@@@
#     @@@@ @@@ @@@@ @@ @@ @@ @@@@@@@
#     @@@@ @@@ @@@@ @@ @@ @@ @@@@@@@
#     @@@@ @@@ @@@@ @@ @@ @@ @@@@@@@
#     @@@@ @@@ @@@@ @@ @@ @@ @@@@@@@
#     @@@@ @@@ @@@@ @@ @@ @@ @@@@@@@
      @@@@ @@@ @@@@ @@ @@ @@ @@@@@@@
```

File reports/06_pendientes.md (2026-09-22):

# Lista de pendientes

Generado automaticamente el 2026-09-21 por `clau3d informe`.
No editar a mano: los numeros salen de `data/components.yaml`.

- Mision: CLAU - CubeSat Laser per a Aplicacions Ultrasegures
- Norma: CubeSat Design Specification Rev. 14.1, The CubeSat Program, Cal Poly SLO
- Estado del layout: **confirmada** (31 piezas colocadas)

Total de huecos abiertos: **141**, de los cuales **63** son TBD sin ninguna aproximacion y **78** son SUPUESTOS: numeros que se ha inventado este repositorio para poder dibujar y colocar la pieza.

> **Un supuesto no es un dato.** No suma en los presupuestos de masa ni de potencia, se dibuja en gris y aparece aqui hasta que alguien lo sustituya por una cifra con fuente. La lista de abajo es, literalmente, lo que hay que preguntar.

## AAC Clyde Space (6)

| componente | magnitud | estado | valor modelado | que falta |
|---|---|---|---|---|
| adcs_iadcs400 | adcs_iadcs400.masa | TBD | - | Masa exacta de la configuracion elegida |
| adcs_iadcs420 | adcs_iadcs420.masa | TBD | - | Masa del iADCS4-20. No hay ficha publica de este producto. |
| antena_quasar_wsant | antena_quasar_wsant.dimensiones | supuesto | `[82.0, 82.0, 10.0]` | Dimensiones reales, ganancia, diagrama de radiacion y cara de montaje |
| antena_quasar_wsant | antena_quasar_wsant.masa | TBD | - | Masa |
| radio_uhf_pulsar_vutrx | radio_uhf_pulsar_vutrx.dimensiones | TBD | - | Dimensiones |
| radio_uhf_pulsar_vutrx | radio_uhf_pulsar_vutrx.masa | TBD | - | Masa |

## AAC Clyde Space / Equipo de potencia de ACSAR (1)

| componente | magnitud | estado | valor modelado | que falta |
|---|---|---|---|---|
| paneles_photon_side | paneles_photon_side.dimensiones | supuesto | `[209.3, 3.5, 349.0]` | Contorno real de cada tamano de PHOTON-SIDE (1U/2U/3U/6U) y cual de ellos se monta en cada cara |

## ACSAR (decision de mision aun abierta) (2)

| componente | magnitud | estado | valor modelado | que falta |
|---|---|---|---|---|
| propulsion | propulsion.dimensiones | TBD | - | Modelo de propulsor y sus dimensiones |
| propulsion | propulsion.masa | TBD | - | Masa del propulsor elegido |

## Aperture Optical Sciences (2)

| componente | magnitud | estado | valor modelado | que falta |
|---|---|---|---|---|
| telescopio_cassegrain | telescopio_cassegrain.masa | TBD | - | Masa |
| telescopio_cassegrain | telescopio_cassegrain.longitud_optica | TBD | - | Longitud del tubo. Interesa distancia focal larga; se admite acortar. |

## Equipo de PAT / de mision de ACSAR (2)

| componente | magnitud | estado | valor modelado | que falta |
|---|---|---|---|---|
| integracion | integracion.optica.punto_de_adelanto | supuesto | `50.7` | Punto de adelanto maximo del enlace, del analisis de mision (orbita y geometria de los pases) |
| integracion | integracion.optica.potencia_beacon_bajada | supuesto | `100.0` | Potencia optica de bajada del presupuesto de enlace (divergencia, distancia, sensibilidad del receptor de la estacion) |

## Equipo de PAT / de optica de ACSAR (1)

| componente | magnitud | estado | valor modelado | que falta |
|---|---|---|---|---|
| colimador_beacon_bajada | colimador_beacon_bajada.dimensiones | supuesto | `[8.0, 12.0, 8.0]` | Colimador elegido, su envolvente real y el diametro de haz que entrega, que es lo que tiene que cuadrar con la apertura de D2 |

## Equipo de PAT de ACSAR (8)

| componente | magnitud | estado | valor modelado | que falta |
|---|---|---|---|---|
| integracion | integracion.optica.aislamiento_camara_a_1064 | TBD | - | Aislamiento total medido del beacon de bajada (1064 nm, 100 mW) en el sensor de la camara de seguimiento: la suma de la reflexion de D2, el filtro de banda estrecha de 976 nm y la ceguera del silicio a 1064. |
| camara_beacon | camara_beacon.dimensiones | supuesto | `[30.0, 26.0, 26.0]` | Modelo de sensor, distancia focal del objetivo, campo de vision exigido por el lazo de apuntado y espesor del filtro de banda estrecha de 976 nm |
| camara_beacon | camara_beacon.masa | TBD | - | Masa del sensor elegido |
| laser_beacon_bajada | laser_beacon_bajada.dimensiones | supuesto | `[40.0, 20.0, 15.0]` | Modelo del modulo elegido, potencia optica real, consumo electrico y su interfaz termica contra la bandeja |
| laser_beacon_bajada | laser_beacon_bajada.masa | TBD | - | Masa del modulo de beacon elegido |
| colimador_beacon_bajada | colimador_beacon_bajada.masa | TBD | - | Masa del colimador elegido con su soporte |
| fotodiodo_monitor_beacon | fotodiodo_monitor_beacon.dimensiones | supuesto | `[12.0, 12.0, 12.0]` | Modelo de fotodiodo, encapsulado y electronica de acondicionamiento |
| fotodiodo_monitor_beacon | fotodiodo_monitor_beacon.masa | TBD | - | Masa del fotodiodo con su soporte y su acondicionamiento |

## Equipo de electronica de ACSAR (12)

| componente | magnitud | estado | valor modelado | que falta |
|---|---|---|---|---|
| integracion | integracion.coaxial.radio_curvatura_modelado | supuesto | `25.0` | Radio minimo de curvatura del coaxial elegido. Es el mismo hueco que 'cables_rf_moduladores.radio_minimo_curvatura'. |
| integracion | integracion.holgura_conector | TBD | - | Holgura de insercion por tipo de conector (coaxial RF, AVIM optico, conectores de datos) |
| pcb1_control_qkd | pcb1_control_qkd.dimensiones | supuesto | `[95.89, 90.17, 15.0]` | Altura real de la tarjeta, que la fija el componente mas alto (la FPGA y su disipador, si lleva). Y confirmar el contorno PC104. |
| pcb1_control_qkd | pcb1_control_qkd.masa | TBD | - | Masa de la tarjeta poblada |
| pcb2_drivers_opticos | pcb2_drivers_opticos.dimensiones | supuesto | `[95.89, 90.17, 15.0]` | Altura real de la tarjeta. Los drivers RF y el del Peltier son los candidatos a componente mas alto. Y confirmar el contorno PC104. |
| pcb2_drivers_opticos | pcb2_drivers_opticos.masa | TBD | - | Masa de la tarjeta poblada |
| pcb3_pat | pcb3_pat.dimensiones | supuesto | `[95.89, 90.17, 15.0]` | Altura real de la tarjeta, y si el driver del FSM es de alta tension (un driver piezo de 120 V ocupa bastante mas que uno de MEMS). Es el mismo dato que bloquea la eleccion del FSM. Y confirmar el contorno. |
| pcb3_pat | pcb3_pat.masa | TBD | - | Masa de la tarjeta poblada |
| cables_rf_moduladores | cables_rf_moduladores.dimensiones | TBD | - | Un cable no tiene envolvente hasta que se encamina. Lo que hace falta es el diametro del coaxial elegido y su radio minimo de curvatura; con esos dos, el recorrido se dibuja como KEEP-OUT entre PCB-2 y cada modulador, no como un cuerpo. |
| cables_rf_moduladores | cables_rf_moduladores.masa | TBD | - | Masa por metro del coaxial elegido, y longitud una vez encaminado |
| cables_rf_moduladores | cables_rf_moduladores.diametro_coaxial | TBD | - | Diametro exterior del coaxial elegido (con su cubierta) |
| cables_rf_moduladores | cables_rf_moduladores.radio_minimo_curvatura | TBD | - | Radio minimo de curvatura del coaxial. Es lo que fija el volumen que hay que reservar, y para un coaxial semirrigido no es pequeno. |

## Equipo de estructura de ACSAR (5)

| componente | magnitud | estado | valor modelado | que falta |
|---|---|---|---|---|
| integracion | integracion.pila_pc104.paso_apilamiento | TBD | - | Paso real entre tarjetas (separadores) del chasis elegido |
| integracion | integracion.bandeja.holgura_montaje | supuesto | `2.0` | Holgura de montaje real de la placa contra el chasis, del patron de taladros |
| estructura_6u | estructura_6u.masa | TBD | - | Masa del chasis 6U elegido |
| telescopio_cassegrain | telescopio_cassegrain.optica.lado_larguero_esquina | supuesto | `12.0` | Seccion real de los largueros, del analisis de rigidez del tubo |
| bandeja_optica | bandeja_optica.dimensiones | supuesto | `[117.7, 3.0, 75.4]` | Material, espesor y patron de taladros de la placa, del analisis estructural y termico |

## Equipo de estructura de ACSAR / Aperture Optical Sciences (3)

| componente | magnitud | estado | valor modelado | que falta |
|---|---|---|---|---|
| telescopio_cassegrain | telescopio_cassegrain.optica.espesor_pared_barrilete | supuesto | `1.5` | Espesor y material reales de la pared del barrilete |
| telescopio_cassegrain | telescopio_cassegrain.optica.espesor_mamparo | supuesto | `3.0` | Espesor real de los mamparos |
| telescopio_cassegrain | telescopio_cassegrain.optica.espesor_vane | supuesto | `0.8` | Espesor real de los vanes |

## Equipo de optica / de payload de ACSAR (1)

| componente | magnitud | estado | valor modelado | que falta |
|---|---|---|---|---|
| integracion | integracion.fibra.tolerancia_coaxialidad | supuesto | `0.5` | Tolerancia de alineacion del colimador elegido, y presupuesto de alineacion del montaje |

## Equipo de optica de ACSAR (28)

| componente | magnitud | estado | valor modelado | que falta |
|---|---|---|---|---|
| integracion | integracion.optica.diametro_haz_modelado | supuesto | `7.0` | Diametro de haz de cada tramo (e01 a e05 en data/connections.yaml) y el semiangulo del cono de la apertura. SIGUE SIENDO TBD: lo de aqui es un techo geometrico, no una medida del diseno optico. |
| integracion | integracion.optica.apertura_libre_optica_banco | supuesto | `11.4` | Apertura libre real de la montura elegida para D1, D2 y el espejo de plegado |
| integracion | integracion.optica.borde_dicroico_d1 | supuesto | `1300.0` | Longitud de onda de corte, anchura de la transicion y curvas de transmision y reflexion del divisor elegido |
| integracion | integracion.optica.borde_dicroico_d2 | supuesto | `1020.0` | Longitud de onda de corte, anchura de la transicion y curvas de transmision y reflexion del divisor elegido |
| telescopio_cassegrain | telescopio_cassegrain.optica.diametro_haz_comprimido | TBD | - | Diametro del haz colimado a la salida del telescopio, que es el mismo que entra por la brida trasera desde el FSM. ES EL PARAMETRO QUE LO ACOPLA TODO: fija la magnificacion (M = apertura_libre / este diametro), y con ella la focal del secundario, la separacion entre vertices y el diametro del secundario; y decide si el FSM elegido vale, porque un haz de d mm sobre un espejo a 45 grados deja una huella de d x d*raiz(2). Es el mismo hueco que 'diametro_haz_mm' en e01..e05 de data/connections.yaml. |
| telescopio_cassegrain | telescopio_cassegrain.optica.margen_secundario | supuesto | `1.4` | Sobredimensionado real del secundario (campo de vista y alineacion) |
| telescopio_cassegrain | telescopio_cassegrain.optica.estabilidad_despace_primario_secundario | TBD | - | Estabilidad exigida a la separacion entre el vertice del primario y el del secundario a lo largo de la orbita, en micras. La sensibilidad a desenfoque de un Cassegrain escala con m^2 (1+m), o sea con el cuadrado de la magnificacion del secundario, asi que unas pocas micras de deriva termica entre los dos espejos se comen el presupuesto de frente de onda entero. ES EL REQUISITO QUE DIMENSIONA el tubo metrico (material, seccion, si hace falta invar o CFRP) y la arana, y hoy no existe: el barrilete y los vanes de este modelo estan dibujados con espesores supuestos, no con una rigidez calculada. |
| telescopio_cassegrain | telescopio_cassegrain.optica.holgura_baffle | supuesto | `0.5` | Holgura real entre el haz y el baffle, del analisis de luz parasita |
| telescopio_cassegrain | telescopio_cassegrain.optica.espesor_baffle | supuesto | `0.6` | Espesor real de los baffles |
| telescopio_cassegrain | telescopio_cassegrain.optica.diafragmas_internos | supuesto | `4` | Numero y posicion reales de los diafragmas, del analisis de luz parasita |
| telescopio_cassegrain | telescopio_cassegrain.optica.espesor_diafragma | supuesto | `1.0` | Espesor real de los diafragmas |
| telescopio_cassegrain | telescopio_cassegrain.optica.angulo_exclusion_solar | TBD | - | Angulo de exclusion solar del terminal: a que separacion angular del Sol tiene que seguir funcionando el enlace. Es lo que DIMENSIONA el baffle del primario y el del secundario, y con ellos la obstruccion y el presupuesto de luz parasita. Sin el, los dos baffles de este modelo estan dibujados con un angulo supuesto. |
| telescopio_cassegrain | telescopio_cassegrain.optica.angulo_exclusion_solar_modelado | supuesto | `30.0` | El angulo de verdad, que es 'angulo_exclusion_solar' |
| fsm | fsm.eleccion_de_tecnologia | TBD | - | Elegir entre MEMS (Mirrorcle, herencia CLICK-A, espejo de 5 mm) y piezo (PI S-331). Se modela el MEMS porque es el que tiene cota publicada clara; eso NO es la eleccion. La alternativa piezo esta en el catalogo como 'fsm_piezo_pi_s331'. |
| fsm | fsm.soporte | TBD | - | Soporte de vuelo del MEMS: el encapsulado DIP24 no se atornilla solo a un banco optico. Es lo que decide el volumen real de esta pieza. |
| dicroico_d1 | dicroico_d1.dimensiones | supuesto | `[16.0, 16.0, 16.0]` | Divisor y montura elegidos, con su apertura libre, sus longitudes de onda de corte y la envolvente real del soporte |
| dicroico_d1 | dicroico_d1.masa | TBD | - | Masa del divisor y su soporte |
| dicroico_d2 | dicroico_d2.dimensiones | supuesto | `[16.0, 16.0, 16.0]` | Divisor y montura elegidos, con su apertura libre, su longitud de onda de corte y la envolvente real del soporte |
| dicroico_d2 | dicroico_d2.masa | TBD | - | Masa del divisor y su soporte |
| trampa_luz_d1 | trampa_luz_d1.dimensiones | supuesto | `[15.0, 15.0, 15.0]` | Tipo de absorbedor, su envolvente y el rechazo exigido |
| trampa_luz_d1 | trampa_luz_d1.masa | TBD | - | Masa de la trampa elegida |
| trampa_luz_d2 | trampa_luz_d2.dimensiones | supuesto | `[15.0, 15.0, 15.0]` | Tipo de absorbedor, su envolvente y el rechazo exigido |
| trampa_luz_d2 | trampa_luz_d2.masa | TBD | - | Masa de la trampa elegida |
| espejo_plegado_cuantico | espejo_plegado_cuantico.dimensiones | supuesto | `[16.0, 16.0, 16.0]` | Espejo y montura elegidos, con su apertura libre y la envolvente real del soporte |
| espejo_plegado_cuantico | espejo_plegado_cuantico.masa | TBD | - | Masa del espejo y su soporte |
| espejo_plegado_cuantico | espejo_plegado_cuantico.retardancia_45_1550 | TBD | - | DIFERENCIA DE FASE s-p DEL RECUBRIMIENTO A 45 GRADOS Y 1550 nm, CON LA CURVA DE FASE MEDIDA, no solo la reflectancia. Hay que especificar PLATA PROTEGIDA u ORO PROTEGIDO exigiendo esa curva al fabricante: la reflectancia alta es facil y la casi todos los recubrimientos la dan, pero la retardancia a 45 grados es lo que transforma los estados de polarizacion, y casi ningun catalogo la publica. LO QUE SE PIDE ES ESTABILIDAD, NO VALOR ABSOLUTO: ver la nota. |
| colimador | colimador.dimensiones | supuesto | `[28.0, 12.0, 12.0]` | Diametro del haz colimado y modelo de colimador. Es el mismo dato que bloquea los keep-outs del camino optico. |
| colimador | colimador.masa | TBD | - | Masa del colimador elegido |

## Equipo de optica de ACSAR / Equipo de estacion de tierra (1)

| componente | magnitud | estado | valor modelado | que falta |
|---|---|---|---|---|
| integracion | integracion.optica.lamina_cuarto_onda_fija | TBD | - | QUE PAR DE BASES USA EL ENLACE, que es lo que decide si hace falta una lamina de cuarto de onda fija. Dos opciones, y las dos son validas para BB84: (a) SIN LAMINA: el esquema ICFO de un solo modulador de fase entrega de forma natural las bases D/A y R/L (diagonal y circular). No hace falta ninguna pieza mas, y el camino cuantico no gana ninguna superficie. (b) CON LAMINA: una lamina de cuarto de onda fija a 45 grados DESPUES del codificador convierte esas bases en H/V y D/A, que es el par clasico y el que muchas estaciones de tierra tienen ya montado. BB84 solo necesita dos bases mutuamente insesgadas, y los dos pares lo son, asi que esto NO es una decision de fisica del protocolo: es una decision de COMPATIBILIDAD CON LA ESTACION DE TIERRA. |

## Equipo de payload / Equipo de ADCS de ACSAR (1)

| componente | magnitud | estado | valor modelado | que falta |
|---|---|---|---|---|
| aislador | aislador.momento_dipolar_magnetico | TBD | - | MOMENTO DIPOLAR MAGNETICO RESIDUAL DE LA PIEZA. Un aislador lleva un ROTADOR DE FARADAY con IMAN PERMANENTE: no es un componente pasivo desde el punto de vista magnetico. Ese iman lo ve el magnetometro del ADCS y suma al dipolo residual del satelite, que es lo que produce par perturbador contra el campo terrestre. Con dos aisladores (si el butterfly del laser lleva uno interno) se suman. |

## Equipo de payload / de seguridad de ACSAR (1)

| componente | magnitud | estado | valor modelado | que falta |
|---|---|---|---|---|
| integracion | integracion.optica.defensa_troya_espacio_libre | TBD | - | QUE DEFENSA CONTRA CABALLO DE TROYA VA EN ESPACIO LIBRE, entre el colimador y el telescopio. Es una pregunta de SEGURIDAD, no de mecanica, y sale de corregir lo que se dijo del vigia del acoplador: el fotodiodo de vigilancia esta detras del VOA visto desde el canal, asi que la luz de sondeo que un atacante meta por la apertura le llega atenuada por el VOA en el camino de ida Y en el de vuelta. Con un VOA que lleva la senal a fracciones de foton eso son decenas de dB dos veces: el vigia sirve de ultimo recurso, no de defensa. La defensa tiene que estar donde el sondeo todavia no se ha atenuado, o sea en el camino libre. Las opciones habituales son un aislador o circulador de espacio libre, un filtro de banda estrecha a 1550 que cierre la ventana espectral por la que se puede sondear, un tap con fotodiodo mirando la luz que ENTRA por la apertura, o una combinacion. Cada una cuesta una superficie mas en el camino cuantico y hay que pesarla contra lo que se gana. |

## Equipo de payload de ACSAR (18)

| componente | magnitud | estado | valor modelado | que falta |
|---|---|---|---|---|
| integracion | integracion.fibra.radio_minimo_curvatura | TBD | - | Radio minimo de curvatura de la fibra elegida (probablemente PM a 1550 nm) |
| integracion | integracion.fibra.radio_curvatura_modelado | supuesto | `30.0` | Radio minimo de curvatura real, que es 'radio_minimo_curvatura' |
| integracion | integracion.fibra.longitud_protector_empalme | supuesto | `60.0` | Protector de empalme elegido y su tramo recto real |
| integracion | integracion.fibra.recubrimiento_empalme_post_codificacion | TBD | - | SI EL EMPALME POST-CODIFICACION SE PUEDE RECUBRIR (recoating) EN VEZ DE PROTEGER CON FERULA, y cuanto tramo rigido deja si se hace. Un empalme recubierto -- se repone el acrilato sobre la fusion, sin varilla metalica ni termorretractil -- devuelve a la fibra su diametro y su flexibilidad originales, asi que el tramo inmovilizado baja de los 60 mm de 'longitud_protector_empalme' a unos pocos milimetros. En la fila del tramo recto eso son del orden de +22 mm de margen, que es mas de lo que hoy sobra entero. NO SE APLICA, se anota: cambia la fiabilidad mecanica del unico empalme que queda en un tramo que ademas tiene prohibido curvarse, y eso es una decision de payload con un ensayo de vibracion detras, no una cota que este repositorio pueda suponer. Si se decide, se sustituye 'longitud_protector_empalme' por el tramo rigido del recoating y el chequeo 'fibra_post_codificacion' lo recalcula solo. |
| integracion | integracion.fibra.longitud_boot_modelada | supuesto | `20.0` | Tipo de conector o protector y su tramo recto de salida |
| voa | voa.dimensiones | supuesto | `[35.0, 5.5, 5.5]` | Modelo de VOA elegido y su envolvente |
| voa | voa.masa | TBD | - | Masa del VOA elegido |
| atenuador_fijo | atenuador_fijo.dimensiones | supuesto | `[25.0, 5.5, 5.5]` | Modelo de atenuador fijo elegido y su envolvente |
| atenuador_fijo | atenuador_fijo.masa | TBD | - | Masa del atenuador fijo elegido |
| aislador | aislador.dimensiones | supuesto | `[35.0, 5.5, 5.5]` | Modelo de aislador elegido y su envolvente |
| aislador | aislador.masa | TBD | - | Masa del aislador elegido |
| aislador | aislador.aislamiento | supuesto | `50.0` | Aislamiento del aislador elegido, medido a 1550 nm |
| filtro_espectral | filtro_espectral.dimensiones | supuesto | `[40.0, 5.5, 5.5]` | Modelo de filtro elegido, su ancho de banda y su envolvente |
| filtro_espectral | filtro_espectral.masa | TBD | - | Masa del filtro elegido |
| filtro_espectral | filtro_espectral.ancho_banda | supuesto | `0.8` | Ancho espectral real del pulso del DFB conmutado en ganancia, y ancho de banda del filtro elegido |
| acoplador_monitor | acoplador_monitor.dimensiones | supuesto | `[60.0, 20.0, 12.0]` | Modelo de acoplador 2x2 y de los dos fotodiodos, y si van en la bandeja o montados en PCB-2 |
| acoplador_monitor | acoplador_monitor.masa | TBD | - | Masa del acoplador 2x2 y los dos fotodiodos |
| acoplador_monitor | acoplador_monitor.razon_acoplamiento | supuesto | `[99.0, 1.0]` | Razon de acoplamiento del acoplador elegido, y sensibilidad del fotodiodo, que es lo que la fija |

## Equipo de payload de ACSAR (medida, no ficha) (1)

| componente | magnitud | estado | valor modelado | que falta |
|---|---|---|---|---|
| integracion | integracion.fibra.sensibilidad_termica_fase_pm | TBD | - | SENSIBILIDAD TERMICA DE LA FASE ENTRE LOS DOS EJES DE LA FIBRA PM, MEDIDA, en rad por metro y por kelvin. Es lo que fija CUANTA FIBRA POST-CODIFICACION ES TOLERABLE, y por tanto si el tramo recto que el layout reserva sirve o hay que acortarlo todavia mas. Por que importa solo despues del codificador: antes, la luz va en polarizacion lineal fija alineada al eje lento, que ES un autoestado de la fibra, y la birrefringencia no le hace nada. Despues, los estados diagonales (y los circulares) viajan a 45 grados de los ejes, NO son autoestados, y la birrefringencia les mete una fase proporcional a la longitud que ademas DERIVA CON LA TEMPERATURA. El resultado seria una base limpia y la otra rota, que es la peor forma de fallar: el enlace parece funcionar. |

## Equipo de potencia de ACSAR (3)

| componente | magnitud | estado | valor modelado | que falta |
|---|---|---|---|---|
| bateria_optimus_30 | bateria_optimus_30.cantidad | TBD | - | Numero de modulos de bateria N segun el presupuesto de energia |
| paneles_photon_side | paneles_photon_side.cantidad | TBD | - | Numero de caras pobladas y tamano de cada una |
| paneles_photon_side | paneles_photon_side.masa | TBD | - | Masa total segun el numero de caras pobladas (la ficha da 135 g por cara de 3U) |

## Este repositorio, tras fijar el layout (1)

| componente | magnitud | estado | valor modelado | que falta |
|---|---|---|---|---|
| bandeja_optica | bandeja_optica.masa | TBD | - | Masa de la placa, que sale del contorno y el material una vez fijado el layout |

## Exail (8)

| componente | magnitud | estado | valor modelado | que falta |
|---|---|---|---|---|
| mod_intensidad_mxer_ln_10 | mod_intensidad_mxer_ln_10.masa | TBD | - | Masa del encapsulado de grado espacial |
| mod_intensidad_mxer_ln_10 | mod_intensidad_mxer_ln_10.fibra_entrada.dimensiones | supuesto | `[10.0, 3.0, 3.0]` | Diametro del protector de fibra del encapsulado de grado espacial |
| mod_intensidad_mxer_ln_10 | mod_intensidad_mxer_ln_10.fibra_salida.dimensiones | supuesto | `[10.0, 3.0, 3.0]` | Diametro del protector de fibra del encapsulado de grado espacial |
| mod_fase_mpz_ln_10 | mod_fase_mpz_ln_10.masa | TBD | - | Masa del encapsulado de grado espacial |
| mod_fase_mpz_ln_10 | mod_fase_mpz_ln_10.guia_bipolarizacion | TBD | - | SI LA GUIA DE LiNbO3 DEL MPZ-LN-10 TRANSMITE LAS DOS POLARIZACIONES (TE y TM). Las guias de INTERCAMBIO PROTONICO guian una sola y se comportan como un polarizador integrado: con una de esas, el esquema de codificacion de polarizacion con UN SOLO modulador de fase es IMPOSIBLE, no peor. Solo una guia bipolarizacion (difusion de titanio o equivalente) permite meter la luz a 45 grados de los ejes y desfasar una componente contra la otra. |
| mod_fase_mpz_ln_10 | mod_fase_mpz_ln_10.pigtail_salida_minimo | TBD | - | Longitud minima de pigtail de salida que Exail puede suministrar en el encapsulado de grado espacial, y SI OFRECE SALIDA CON COLIMADOR INTEGRADO. Lo segundo eliminaria el empalme posterior al codificador y con el los 60 mm de 'integracion.fibra.longitud_protector_empalme', que es justo lo que hoy hace que el tramo recto no quepa en la franja (ver el chequeo 'fibra_post_codificacion'). |
| mod_fase_mpz_ln_10 | mod_fase_mpz_ln_10.fibra_entrada.dimensiones | supuesto | `[10.0, 3.0, 3.0]` | Diametro del protector de fibra del encapsulado de grado espacial |
| mod_fase_mpz_ln_10 | mod_fase_mpz_ln_10.fibra_salida.dimensiones | supuesto | `[10.0, 3.0, 3.0]` | Diametro del protector de fibra del encapsulado de grado espacial |

## Exail / Equipo de electronica de ACSAR (2)

| componente | magnitud | estado | valor modelado | que falta |
|---|---|---|---|---|
| mod_intensidad_mxer_ln_10 | mod_intensidad_mxer_ln_10.rf.dimensiones | supuesto | `[6.1, 10.0, 6.1]` | Profundidad del conector RF, y holgura de insercion del coaxial |
| mod_fase_mpz_ln_10 | mod_fase_mpz_ln_10.rf.dimensiones | supuesto | `[6.1, 10.0, 6.1]` | Profundidad del conector RF, y holgura de insercion del coaxial |

## Exail / Equipo de payload de ACSAR (1)

| componente | magnitud | estado | valor modelado | que falta |
|---|---|---|---|---|
| mod_intensidad_mxer_ln_10 | mod_intensidad_mxer_ln_10.extincion_suficiente_para_vacio | TBD | - | SI LA RAZON DE EXTINCION DEL MXER-LN-10 DE GRADO ESPACIAL BASTA PARA EL ESTADO VACIO, o hacen falta DOS EN CASCADA. El metodo de decoy necesita tres niveles -- senal, decoy y vacio -- y el vacio tiene que ser vacio de verdad: lo que se escape por ahi es un fondo que el analisis de seguridad se come entero. La ficha garantiza la extincion entre 0 y +70 C pero no dice cuanta, y la extincion de un Mach-Zehnder en el punto nulo depende ademas de lo bien que se mantenga el bias. |

## Gooch & Housego (3)

| componente | magnitud | estado | valor modelado | que falta |
|---|---|---|---|---|
| laser_dfb_1550 | laser_dfb_1550.masa | TBD | - | Masa del modulo butterfly con Peltier |
| laser_dfb_1550 | laser_dfb_1550.pines_btf14.dimensiones | supuesto | `[30.0, 15.3, 4.0]` | Cotas de la fila de pines del modulo elegido |
| laser_dfb_1550 | laser_dfb_1550.pines_btf14_b.dimensiones | supuesto | `[30.0, 15.3, 4.0]` | Cotas de la fila de pines del modulo elegido |

## ICFO / Equipo de payload de ACSAR (1)

| componente | magnitud | estado | valor modelado | que falta |
|---|---|---|---|---|
| mod_fase_mpz_ln_10 | mod_fase_mpz_ln_10.configuracion_esquema_icfo | TBD | - | SI EL ESQUEMA ES DE PASO SIMPLE con entrada a 45 grados, EN LAZO SAGNAC o DE IDA Y VUELTA. No es un detalle de implementacion: un esquema en lazo anade componentes en el camino -- un circulador o un divisor de polarizacion -- y ESO CAMBIA LA CADENA declarada en data/connections.yaml y la reserva de volumen de la franja. |

## ID Quantique (1)

| componente | magnitud | estado | valor modelado | que falta |
|---|---|---|---|---|
| qrng_idq20mc1_s3 | qrng_idq20mc1_s3.masa | TBD | - | Masa por unidad |

## Mirrorcle Technologies / Equipo de optica de ACSAR (1)

| componente | magnitud | estado | valor modelado | que falta |
|---|---|---|---|---|
| fsm | fsm.masa | TBD | - | Masa del MEMS con su soporte de vuelo |

## Oscar (ACSAR) / AAC Clyde Space (3)

| componente | magnitud | estado | valor modelado | que falta |
|---|---|---|---|---|
| adcs_iadcs420 | adcs_iadcs420.modelo_confirmado | TBD | - | Confirmar QUE ADCS lleva CLAU, iADCS400 o iADCS4-20, y por que el modelo preliminar trae el 4-20 cuando el brief cita el 400. Hasta saberlo hay dos componentes en el catalogo para un solo hueco de la pila. |
| obc_kryten_m3_plus | obc_kryten_m3_plus.part_number_verificado | TBD | - | Confirmar que el STEP 3D-25-02929 RevJ es el Kryten-M3-PLUS. Hasta entonces la geometria dibujada es de referencia, no de ficha. |
| bateria_optimus_30 | bateria_optimus_30.part_number_verificado | TBD | - | Confirmar que el STEP 3D-01-02686 RevA es el Optimus-30, y cuantos Wh da: el STEP trae 8 celdas, y de ahi no se deduce la capacidad. |

## Oscar (ACSAR) / Aperture Optical Sciences (21)

| componente | magnitud | estado | valor modelado | que falta |
|---|---|---|---|---|
| telescopio_cassegrain | telescopio_cassegrain.dimensiones | supuesto | `[95.4, 95.4, 227.0]` | Diametro exterior del barrilete y longitud optica real. YA EXISTE un concepto en formato nativo SolidWorks (Telescopio_concepto.SLDPRT, entrega "Preliminar viability model" del 2026-09-20), ilegible. Hace falta reexportarlo a STEP AP214 o AP242 y dejarlo en la ruta de 'step_esperado'. Ver cad/vendor/MANIFEST.yaml, seccion 'sin_convertir'. |
| telescopio_cassegrain | telescopio_cassegrain.optica.focal_primario | supuesto | `200.0` | Focal real del primario, del diseno optico de Aperture Optical Sciences |
| telescopio_cassegrain | telescopio_cassegrain.optica.conica_primario | supuesto | `-1.0` | Constante conica real del primario del diseno optico |
| telescopio_cassegrain | telescopio_cassegrain.optica.conica_secundario | supuesto | `-1.0` | Constante conica real del secundario del diseno optico |
| telescopio_cassegrain | telescopio_cassegrain.optica.distancia_focal_trasera | supuesto | `40.0` | Distancia focal trasera del diseno focal, si se eligiera esa configuracion |
| telescopio_cassegrain | telescopio_cassegrain.optica.margen_agujero_primario | supuesto | `4.0` | Diametro real del agujero central del primario |
| telescopio_cassegrain | telescopio_cassegrain.optica.margen_substrato_primario | supuesto | `1.0` | Diametro exterior real del sustrato del primario |
| telescopio_cassegrain | telescopio_cassegrain.optica.seccion_barrilete | supuesto | `[95.4, 95.4]` | Contorno exterior real del barrilete |
| telescopio_cassegrain | telescopio_cassegrain.optica.margen_agujero_entrada | supuesto | `2.0` | Diametro real del agujero de entrada |
| telescopio_cassegrain | telescopio_cassegrain.optica.espesor_espejo_primario | supuesto | `8.0` | Espesor y material reales del sustrato del primario |
| telescopio_cassegrain | telescopio_cassegrain.optica.espesor_espejo_secundario | supuesto | `4.0` | Espesor y material reales del sustrato del secundario |
| telescopio_cassegrain | telescopio_cassegrain.optica.altura_celda | supuesto | `3.0` | Altura real de la celda isostatica del primario |
| telescopio_cassegrain | telescopio_cassegrain.optica.flexures | supuesto | `3` | Numero y tipo reales de flexures de la celda |
| telescopio_cassegrain | telescopio_cassegrain.optica.radio_circulo_flexures | supuesto | `40.0` | Radio real del circulo de apoyo de la celda |
| telescopio_cassegrain | telescopio_cassegrain.optica.angulo_primer_flexure | supuesto | `45.0` | Orientacion real de la celda respecto al barrilete |
| telescopio_cassegrain | telescopio_cassegrain.optica.seccion_flexure | supuesto | `[6.0, 6.0]` | Seccion real de los flexures |
| telescopio_cassegrain | telescopio_cassegrain.optica.margen_buje_secundario | supuesto | `3.0` | Montura real del secundario |
| telescopio_cassegrain | telescopio_cassegrain.optica.tornillos_colimacion | supuesto | `3` | Mecanismo real de colimacion del secundario |
| telescopio_cassegrain | telescopio_cassegrain.optica.diametro_tornillo_colimacion | supuesto | `3.0` | Tornilleria real de colimacion |
| telescopio_cassegrain | telescopio_cassegrain.optica.vanes | supuesto | `4` | Numero real de vanes de la arana |
| telescopio_cassegrain | telescopio_cassegrain.optica.ancho_vane | supuesto | `6.0` | Geometria real de la arana |

## Oscar (ACSAR) / Equipo de optica de ACSAR (2)

| componente | magnitud | estado | valor modelado | que falta |
|---|---|---|---|---|
| telescopio_cassegrain | telescopio_cassegrain.optica.brida_interfaz_fsm | supuesto | `[40.0, 40.0]` | Interfaz mecanica real telescopio-banco (patron de taladros y plano de referencia) |
| telescopio_cassegrain | telescopio_cassegrain.optica.espesor_brida | supuesto | `3.0` | Espesor real de la brida de interfaz |

## Physik Instrumente (1)

| componente | magnitud | estado | valor modelado | que falta |
|---|---|---|---|---|
| fsm_piezo_pi_s331 | fsm_piezo_pi_s331.dimensiones | supuesto | `[50.0, 50.0, 22.0]` | Cotas exteriores del S-331 (plano acotado o STEP) |
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

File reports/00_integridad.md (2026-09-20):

# Integridad del catalogo

Sin problemas: toda magnitud lleva estado y fuente, todo TBD dice que falta y a quien pedirlo, y toda conexion apunta a componentes que existen.

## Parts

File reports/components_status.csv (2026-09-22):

id_drive | id | nombre | categoria | subsistema | referencia_comercial | fuente_geometria | estado_cotas | dimensiones_mm | fuente_cotas | uds | masa_g | estado_masa | colocado | zona | centro_mm | conectores | keep_outs | que_falta | pedir_a
PLAT-08 | estructura_6u | Estructura 6U (chasis) | estructura | estructura |  | aproximado propio: caja | confirmado | 226.3 x 100.0 x 366.0 | CDS Rev 14.1, plano CDS-14-007 | 1 |  | TBD | no
PLAT-04 | adcs_iadcs400 | AAC Clyde Space iADCS400 | plataforma | ADCS | AAC Clyde Space iADCS400 (incluye star tracker ST200) | aproximado propio: caja | confirmado | 95.4 x 95.9 x 67.3 | Brief ACSAR 2026-09-19 (cita ficha AAC Clyde Space iADCS400) | 1 |  | TBD | si | z_plataforma | -60.9, 0.0, 142.6
PLAT-04-ALT | adcs_iadcs420 | AAC Clyde Space iADCS4-20 (alternativa, solo STEP) | plataforma | ADCS | AAC Clyde Space iADCS4-20 (part number IADCS420-ASM-ST-1.0) | STEP de fabricante | referencia | 95.4 x 93.9 x 74.1 | Medido sobre el propio STEP (210 solidos, caja envolvente calculada solido a solido), ya girado a los ejes del catalogo. AAC NO publica ficha del iADCS4-20: el STEP es la unica fuente que hay de este producto, y por eso el estado es 'referencia' y no 'confirmado'. | 1 |  | TBD | no
PLAT-01 | obc_kryten_m3_plus | AAC Clyde Space Kryten-M3-PLUS (OBC con GNSS) | plataforma | OBC | AAC Clyde Space Kryten-M3-PLUS | STEP de fabricante | confirmado | 95.89 x 90.17 x 5.51 | https://www.aac-clyde.space/wp-content/uploads/2021/10/AAC_DataSheet_Kryten.pdf | 1 | 61.9 | confirmado | si | z_plataforma | -60.8, 0.0, 89.3
PLAT-05 | eps_starbuck_nano_plus | AAC Clyde Space Starbuck-Nano-PLUS (EPS) | plataforma | EPS | AAC Clyde Space Starbuck-Nano-PLUS | aproximado propio: caja | confirmado | 95.89 x 90.17 x 20.82 | https://www.aac-clyde.space/wp-content/uploads/2021/11/AAC_DataSheet_Starbuck-Nano.pdf | 1 | 148.0 | confirmado | si | z_plataforma | -60.9, 0.0, 58.8
PLAT-06 | bateria_optimus_30 | AAC Clyde Space Optimus-30 (bateria) | plataforma | EPS | AAC Clyde Space Optimus-30 | STEP de fabricante | confirmado | 95.89 x 90.17 x 21.55 | https://www.aac-clyde.space/wp-content/uploads/2021/11/AAC_DataSheet_Optimus.pdf | 2 | 268.0 | confirmado | si | z_plataforma | -60.9, 0.0, -55.5
PLAT-02 | radio_banda_s_quasar_strx | AAC Clyde Space Quasar-STRX (transceptor banda S) | plataforma | comunicaciones | AAC Clyde Space Quasar-STRX | aproximado propio: caja | referencia | 96.0 x 90.0 x 16.9 | Ficha AAC Pulsar-STX (via brief ACSAR 2026-09-19) | 1 | 100.0 | referencia | si | z_plataforma | -60.8, 0.0, 28.3
PLAT-03 | antena_quasar_wsant | AAC Clyde Space Quasar-WSANT (antena banda S) | plataforma | comunicaciones | AAC Clyde Space Quasar-WSANT | aproximado propio: caja | supuesto | 82.0 x 82.0 x 10.0 | SUPUESTO. AAC no publica las cotas del Quasar-WSANT. 82 x 82 x 10 mm es el orden de magnitud de una antena de parche de banda S para cubesat, que a 2.2 GHz necesita del orden de 80 mm de lado con sustrato ceramico. NO es la ficha de este producto. | 1 |  | TBD | si | z_plataforma | -60.8, 0.0, -175.7 |  |  | Dimensiones reales, ganancia, diagrama de radiacion y cara de montaje | AAC Clyde Space
 | radio_uhf_pulsar_vutrx | AAC Clyde Space Pulsar-VUTRX (UHF, TT&C de respaldo) | plataforma | comunicaciones | AAC Clyde Space Pulsar-VUTRX | sin geometria | TBD |  |  | 1 |  | TBD | no |  |  |  |  | Dimensiones | AAC Clyde Space
PLAT-07 | paneles_photon_side | AAC Clyde Space PHOTON-SIDE (paneles de montaje en cuerpo) | plataforma | EPS | AAC Clyde Space PHOTON-SIDE | aproximado propio: caja | supuesto | 209.3 x 3.5 x 349.0 | El ESPESOR, 3.5 mm, es dato de ficha (altura plegada; ver 'altura_plegada' abajo) y cabe de sobra en los 6.5 mm de protrusion que permite la CDS 14.1 req 2.2.3. El CONTORNO esta derivado, no copiado: es la cara +-Y del 6U (226.3 x 366 mm) menos el ancho de rail confirmado (8.5 mm, req 2.2.5) por cad | 2 |  | TBD | si | exterior | 0.0, 51.8, 0.0 |  |  | Contorno real de cada tamano de PHOTON-SIDE (1U/2U/3U/6U) y cual de ellos se monta en cada cara | AAC Clyde Space / Equipo de potencia de ACSAR
 | propulsion | Modulo de propulsion (opcional) | plataforma | propulsion |  | sin geometria | TBD |  |  | 1 |  | TBD | no |  |  |  |  | Modelo de propulsor y sus dimensiones | ACSAR (decision de mision aun abierta)
OPT-13 | telescopio_cassegrain | Telescopio Cassegrain on-axis, apertura 90 mm | payload_optico | terminal_optico | Aperture Optical Sciences, Cassegrain a medida, apertura 90 mm | aproximado propio: cassegrain (esperando STEP) | supuesto | 95.4 x 95.4 x 227.0 | COTA SUPERIOR, no una medida. Es la ENVOLVENTE que el telescopio reserva, y lo que usan el analisis de volumen y el de interferencias: el modelo detallado es hueco por dentro, y meter ese hueco en el analisis diria que dentro del tubo cabe algo, que es falso. El lado de la seccion es la altura inter | 1 |  | TBD | si | z_payload_telescopio | 36.9, 0.0, 67.2 |  |  | Diametro exterior del barrilete y longitud optica real. YA EXISTE un concepto en formato nativo SolidWorks (Telescopio_concepto.SLDPRT, entrega "Preliminar viability model" del 2026-09-20), ilegible. Hace falta reexportarlo a STEP AP214 o AP242 y dejarlo en la ruta de 'step_esperado'. Ver cad/vendor | Oscar (ACSAR) / Aperture Optical Sciences
OPT-10 | fsm | Espejo de apuntado fino (FSM) - opcion MEMS | payload_optico | terminal_optico | Mirrorcle Technologies, MEMS de dos ejes en encapsulado DIP24 | aproximado propio: caja | referencia | 30.5 x 15.1 x 2.16 | https://mirrorcletech.com/pdf/Mirrorcle_MEMS_Packages_and_Mounts_Guide.pdf | 1 |  | TBD | si | z_payload_banco | 36.9, 0.0, -73.8
OPT-10-ALT | fsm_piezo_pi_s331 | FSM - alternativa piezo PI S-331 (no va a bordo, esta en estudio) | payload_optico | terminal_optico | Physik Instrumente S-331.2SB (plataforma piezo tip/tilt) | aproximado propio: cilindro | supuesto | 50.0 x 50.0 x 22.0 | SUPUESTO. PI publica la masa del S-331 y sus datos mecanicos, pero sus cotas exteriores estan solo en el plano del manual (figura, sin texto extraible). Las de aqui son una reserva del orden correcto para una plataforma tip/tilt de flexion que monta un espejo de 12.7 mm. Lo que SI es dato y esta aba | 1 | 130.0 | confirmado | no |  |  |  |  | Cotas exteriores del S-331 (plano acotado o STEP) | Physik Instrumente
OPT-09 | dicroico_d1 | Dicroico D1 (separacion canal cuantico / beacons) | payload_optico | terminal_optico |  | aproximado propio: caja | supuesto | 16.0 x 16.0 x 16.0 | SUPUESTO. Reserva cubica para el SOPORTE de D1, con el sustrato a 45 grados por dentro. La envolvente va alineada con los ejes porque lo que ocupa es la celda, no el sustrato. BAJADA DE 23 A 16 mm el 2026-09-21 [DECISION ACSAR], al fijar la familia de opticas del banco en Ø12.7 mm (media pulgada). E | 1 |  | TBD | si | z_payload_banco | 61.4, 0.0, -73.8 |  |  | Divisor y montura elegidos, con su apertura libre, sus longitudes de onda de corte y la envolvente real del soporte | Equipo de optica de ACSAR
OPT-15 | dicroico_d2 | Dicroico D2 (separacion beacon de subida / beacon de bajada) | payload_optico | terminal_optico |  | aproximado propio: caja | supuesto | 16.0 x 16.0 x 16.0 | SUPUESTO. Misma reserva cubica que 'dicroico_d1' y por el mismo motivo: lo que ocupa es la celda con el sustrato a 45 grados por dentro, no el sustrato. Bajada de 23 a 16 mm el 2026-09-21 [DECISION ACSAR] al fijar la familia Ø12.7 para las tres piezas planas del banco; el razonamiento entero esta en | 1 |  | TBD | si | z_payload_banco | 61.4, 21.0, -73.8 |  |  | Divisor y montura elegidos, con su apertura libre, su longitud de onda de corte y la envolvente real del soporte | Equipo de optica de ACSAR
OPT-11 | camara_beacon | Camara / sensor de beacon de subida (medida del error de apuntado) | payload_optico | terminal_optico |  | aproximado propio: caja | supuesto | 30.0 x 26.0 x 26.0 | SUPUESTO. Reserva para un sensor pequeno con objetivo corto a 976 nm, INCLUIDO EL FILTRO DE BANDA ESTRECHA que va delante: el filtro no es un cuerpo aparte del catalogo, va dentro de esta reserva, porque modelarlo suelto anade una pieza mas a la fila del brazo. RECUPERADA A UNA RESERVA REALISTA el 2 | 1 |  | TBD | si | z_payload_banco | 33.4, 21.0, -73.8 |  |  | Modelo de sensor, distancia focal del objetivo, campo de vision exigido por el lazo de apuntado y espesor del filtro de banda estrecha de 976 nm | Equipo de PAT de ACSAR
OPT-12 | laser_beacon_bajada | Modulo laser de beacon de bajada (1064 nm), fiberizado | payload_bandeja | bandeja_optica |  | aproximado propio: caja | supuesto | 40.0 x 20.0 x 15.0 | SUPUESTO. Reserva para un modulo de diodo laser de 1064 nm con salida FIBERIZADA, del orden del butterfly de 14 pines del DFB (37.4 x 12.7 x 7.8) mas su interfaz termica: 40 x 20 x 15 mm. Ya NO incluye ni la optica de colimacion ni el camino en espacio libre -- eso es 'colimador_beacon_bajada' --, y | 1 |  | TBD | si | z_payload_bandeja | 84.8, -37.2, -153.1 |  | fibra_laser_beacon_bajada_salida | Modelo del modulo elegido, potencia optica real, consumo electrico y su interfaz termica contra la bandeja | Equipo de PAT de ACSAR
OPT-20 | colimador_beacon_bajada | Colimador de fibra del beacon de bajada (1064 nm) | payload_optico | terminal_optico |  | aproximado propio: cilindro | supuesto | 8.0 x 12.0 x 8.0 | SUPUESTO. Reserva para un colimador de fibra compacto: barrilete cilindrico de 8 mm de diametro y 12 mm de largo, con la fibra entrando por la cara opuesta al haz. Referencia de que esa envolvente existe: OZ Optics LPC-04, cuya carcasa es de Ø8. NO es una eleccion, es la comprobacion de que un colim | 1 |  | TBD | si | z_payload_banco | 61.4, 40.0, -73.8 |  | fibra_colimador_beacon_bajada_entrada | Colimador elegido, su envolvente real y el diametro de haz que entrega, que es lo que tiene que cuadrar con la apertura de D2 | Equipo de PAT / de optica de ACSAR
OPT-16 | fotodiodo_monitor_beacon | Fotodiodo de monitorizacion de potencia del beacon de bajada | payload_optico | terminal_optico |  | aproximado propio: caja | supuesto | 12.0 x 12.0 x 12.0 | SUPUESTO. Reserva para un fotodiodo en encapsulado TO con su soporte y una lente de concentracion. Un cubo de 12 mm es el orden de magnitud; NO es ningun producto. Al ir en un puerto de fuga no le hacen falta ni apertura grande ni alineacion fina, asi que es la pieza del brazo cuya cota menos puede | 1 |  | TBD | si | z_payload_banco | 80.4, 21.0, -73.8 |  |  | Modelo de fotodiodo, encapsulado y electronica de acondicionamiento | Equipo de PAT de ACSAR
OPT-17 | trampa_luz_d1 | Trampa de luz del cuarto puerto de D1 | payload_optico | terminal_optico |  | aproximado propio: caja | supuesto | 15.0 x 15.0 x 15.0 | SUPUESTO. Reserva para un absorbedor de haz de banco: cavidad o cono negro con su soporte. Un cubo de 15 mm es el orden de magnitud de una trampa para un haz colimado de pocos milimetros y potencias de microvatios; NO es ningun producto. La cota real depende del angulo de aceptacion que haga falta p | 1 |  | TBD | si | z_payload_banco | 61.4, -20.5, -73.8 |  |  | Tipo de absorbedor, su envolvente y el rechazo exigido | Equipo de optica de ACSAR
OPT-18 | trampa_luz_d2 | Trampa de luz del cuarto puerto de D2 (alternativa al fotodiodo) | payload_optico | terminal_optico |  | aproximado propio: caja | supuesto | 15.0 x 15.0 x 15.0 | SUPUESTO. Misma reserva que 'trampa_luz_d1' y por el mismo motivo. | 1 |  | TBD | no |  |  |  |  | Tipo de absorbedor, su envolvente y el rechazo exigido | Equipo de optica de ACSAR
OPT-19 | espejo_plegado_cuantico | Espejo de plegado del canal cuantico (plano metalico a 45 grados) | payload_optico | terminal_optico |  | aproximado propio: caja | supuesto | 16.0 x 16.0 x 16.0 | SUPUESTO, y ACOTADO POR LOS DOS LADOS. Por abajo lo acota EL HAZ: un haz de d mm que incide a 45 grados deja una huella de d x d*raiz(2) sobre el espejo -- el mismo razonamiento que decide si el MEMS del FSM vale, ver CLAUDE.md 4.7(c) --, asi que con el diametro de haz modelado ('integracion.optica. | 1 |  | TBD | si | z_payload_banco | 95.5, 0.0, -73.8 |  |  | Espejo y montura elegidos, con su apertura libre y la envolvente real del soporte | Equipo de optica de ACSAR
OPT-08 | colimador | Colimador fibra a espacio libre | payload_optico | terminal_optico |  | aproximado propio: cilindro | supuesto | 28.0 x 12.0 x 12.0 | SUPUESTO. Reserva para un colimador de fibra de banco: barrilete cilindrico de unos 12 mm de diametro. NO es ningun producto. El diametro del barrilete lo fija el del haz colimado, que es TBD, asi que esta cifra se movera con el. ACOTADA POR ARRIBA POR EL BANCO, ademas: el FSM tiene que estar sobre | 1 |  | TBD | si | z_payload_franja | 95.5, 0.0, -32.3 |  | fibra_colimador_beacon_bajada_entrada | Diametro del haz colimado y modelo de colimador. Es el mismo dato que bloquea los keep-outs del camino optico. | Equipo de optica de ACSAR
OPT-14 | bandeja_optica | Bandeja optica (placa mecanica, no PCB) | payload_bandeja | bandeja_optica |  | aproximado propio: caja | supuesto | 117.7 x 3.0 x 75.4 | EL CONTORNO NO SE ELIGE: es la zona z_payload_bandeja menos 'integracion.bandeja.holgura_montaje' (2 mm) por lado, en X y en Z. Con la longitud del telescopio en 227 mm esa zona mide 121.7 x 79.4, asi que la placa mide 117.7 x 75.4. EL ESPESOR de 3 mm si esta inventado, y la holgura de 2 mm tambien: | 1 |  | TBD | si | z_payload_bandeja | 50.0, -46.2, -141.0 |  |  | Material, espesor y patron de taladros de la placa, del analisis estructural y termico | Equipo de estructura de ACSAR
OPT-01 | laser_dfb_1550 | Laser DFB 1550 nm, Gooch & Housego (modulo validado para espacio) | payload_bandeja | bandeja_optica | Gooch & Housego, modulo DFB 1550 nm ESCC-23201 | aproximado propio: caja | referencia | 37.4 x 12.7 x 7.8 | https://www.phix.com/wp-content/uploads/2025/10/PHIX-BTF14-Design-Guidelines.pdf | 1 |  | TBD | si | z_payload_bandeja | 13.8, -40.8, -153.1 | pines_btf14(electrico, supuesto); pines_btf14_b(electrico, supuesto) | fibra_laser_dfb_1550_salida | Plano mecanico del modulo G&H ESCC-23201 y, sobre todo, el disipador o la interfaz termica que necesitan sus 4.1 W. | Gooch & Housego / Equipo termico de ACSAR
OPT-02 | mod_intensidad_mxer_ln_10 | Exail MXER-LN-10 (modulador de intensidad, grado espacial EM/NS-FM/FM) | payload_bandeja | bandeja_optica | Exail MXER-LN-10, encapsulado de grado espacial EM/NS-FM/FM | aproximado propio: caja | confirmado | 110.0 x 15.0 x 9.7 | https://www.exail.com/media-file/7854/exail-datasheet-em-ns-fm-fm-mxer-ln-10-space-grade-components.pdf | 1 |  | TBD | si | z_payload_franja | 97.7, -28.0, 18.7 | rf(coaxial, supuesto); fibra_entrada(fibra, supuesto); fibra_salida(fibra, supuesto) | fibra_mod_intensidad_mxer_ln_10_entrada; coaxial_mod_intensidad_mxer_ln_10
OPT-03 | mod_fase_mpz_ln_10 | Exail MPZ-LN-10 (modulador de fase, codificador de polarizacion) | payload_bandeja | bandeja_optica | Exail MPZ-LN-10 (grado espacial sin ficha publica) | aproximado propio: caja | referencia | 110.0 x 15.0 x 9.7 | https://www.exail.com/media-file/7855/exail-datasheet-em-ns-fm-fm-nir-mpx-ln-01-space-grade-components.pdf | 1 |  | TBD | si | z_payload_franja | 95.6, 5.0, 106.7 | rf(coaxial, supuesto); fibra_entrada(fibra, supuesto); fibra_salida(fibra, supuesto) | fibra_mod_fase_mpz_ln_10_entrada; coaxial_mod_fase_mpz_ln_10
OPT-04 | voa | Atenuador optico variable (VOA) | payload_bandeja | bandeja_optica |  | aproximado propio: cilindro | supuesto | 35.0 x 5.5 x 5.5 | SUPUESTO. Encapsulado cilindrico en linea tipico de los componentes pasivos de fibra de telecomunicaciones (del orden de 5.5 mm de diametro por 35-40 mm de cuerpo). NO es ningun producto: no hay candidato elegido, asi que no hay ficha que copiar. Sirve para reservar un volumen del orden correcto en | 1 |  | TBD | si | z_payload_franja | 97.7, 28.2, 39.2 |  | fibra_voa_entrada; fibra_voa_salida | Modelo de VOA elegido y su envolvente | Equipo de payload de ACSAR
OPT-04-ALT | atenuador_fijo | Atenuador fijo calibrado en tierra (alternativa al VOA) | payload_bandeja | bandeja_optica |  | aproximado propio: cilindro | supuesto | 25.0 x 5.5 x 5.5 | SUPUESTO. Encapsulado cilindrico en linea de un atenuador FIJO, que es mas corto que el variable porque no lleva ni actuador ni electronica: solo el elemento atenuante y los dos empalmes. NO es ningun producto. Se declara para que la alternativa se pueda comparar en volumen, no para dibujarla: al se | 1 |  | TBD | no |  |  |  |  | Modelo de atenuador fijo elegido y su envolvente | Equipo de payload de ACSAR
OPT-05 | aislador | Aislador optico | payload_bandeja | bandeja_optica |  | aproximado propio: cilindro | supuesto | 35.0 x 5.5 x 5.5 | SUPUESTO. Encapsulado cilindrico en linea tipico de los componentes pasivos de fibra de telecomunicaciones (del orden de 5.5 mm de diametro por 35-40 mm de cuerpo). NO es ningun producto: no hay candidato elegido, asi que no hay ficha que copiar. Sirve para reservar un volumen del orden correcto en | 1 |  | TBD | si | z_payload_bandeja | 12.6, -42.0, -120.7 |  | fibra_aislador_entrada; fibra_aislador_salida | Modelo de aislador elegido y su envolvente | Equipo de payload de ACSAR
OPT-06 | filtro_espectral | Filtro espectral | payload_bandeja | bandeja_optica |  | aproximado propio: cilindro | supuesto | 40.0 x 5.5 x 5.5 | SUPUESTO. Encapsulado cilindrico en linea tipico de los componentes pasivos de fibra de telecomunicaciones (del orden de 5.5 mm de diametro por 35-40 mm de cuerpo). NO es ningun producto: no hay candidato elegido, asi que no hay ficha que copiar. Sirve para reservar un volumen del orden correcto en | 1 |  | TBD | si | z_payload_bandeja | 84.8, -42.0, -120.7 |  | fibra_filtro_espectral_entrada; fibra_filtro_espectral_salida | Modelo de filtro elegido, su ancho de banda y su envolvente | Equipo de payload de ACSAR
OPT-07 | acoplador_monitor | Acoplador 2x2 de monitorizacion + dos fotodiodos | payload_bandeja | bandeja_optica |  | aproximado propio: caja | supuesto | 60.0 x 20.0 x 12.0 | SUPUESTO. Reserva para un acoplador de derivacion 2x2 en linea (tubo de unos 60 mm) mas el encapsulado de DOS fotodiodos InGaAs con su transimpedancia: el de monitorizacion hacia delante y el VIGIA DE TROYA hacia atras. NO es ningun producto: no hay candidato elegido. LOS DOS FOTODIODOS VAN DENTRO D | 1 |  | TBD | si | z_payload_franja | 97.7, 35.5, -16.3 |  | fibra_acoplador_monitor_entrada | Modelo de acoplador 2x2 y de los dos fotodiodos, y si van en la bandeja o montados en PCB-2 | Equipo de payload de ACSAR
ELEC-01 | pcb1_control_qkd | PCB-1 Control QKD (FPGA, QRNG, memoria, reloj) | payload_pcb | control_qkd |  | aproximado propio: caja | supuesto | 95.89 x 90.17 x 15.0 | SUPUESTO en la altura. El CONTORNO si sale del catalogo: es el contorno PC104 comun a la gama AAC que usa CLAU (integracion.pila_pc104.contorno, 95.89 x 90.17 mm), y esta PROPUESTO, no confirmado. La ALTURA, 15.0 mm, esta inventada: es la posicion de separador PC/104 (15.24 mm) menos holgura, o sea | 1 |  | TBD | si | z_plataforma | -60.9, 0.0, -9.8 |  |  | Altura real de la tarjeta, que la fija el componente mas alto (la FPGA y su disipador, si lleva). Y confirmar el contorno PC104. | Equipo de electronica de ACSAR
ELEC-02 | pcb2_drivers_opticos | PCB-2 Drivers opticos | payload_pcb | drivers_opticos |  | aproximado propio: caja | supuesto | 95.89 x 90.17 x 15.0 | SUPUESTO en la altura. El CONTORNO si sale del catalogo: es el contorno PC104 comun a la gama AAC que usa CLAU (integracion.pila_pc104.contorno, 95.89 x 90.17 mm), y esta PROPUESTO, no confirmado. La ALTURA, 15.0 mm, esta inventada: es la posicion de separador PC/104 (15.24 mm) menos holgura, o sea | 1 |  | TBD | si | z_plataforma | -60.9, 0.0, -25.0 |  |  | Altura real de la tarjeta. Los drivers RF y el del Peltier son los candidatos a componente mas alto. Y confirmar el contorno PC104. | Equipo de electronica de ACSAR
ELEC-03 | pcb3_pat | PCB-3 PAT (apuntado, adquisicion y seguimiento) | payload_pcb | pat |  | aproximado propio: caja | supuesto | 95.89 x 90.17 x 15.0 | SUPUESTO en la altura. El CONTORNO si sale del catalogo: es el contorno PC104 comun a la gama AAC que usa CLAU (integracion.pila_pc104.contorno, 95.89 x 90.17 mm), y esta PROPUESTO, no confirmado. La ALTURA, 15.0 mm, esta inventada: es la posicion de separador PC/104 (15.24 mm) menos holgura, o sea | 1 |  | TBD | si | z_plataforma | -60.9, 0.0, 5.4 |  |  | Altura real de la tarjeta, y si el driver del FSM es de alta tension (un driver piezo de 120 V ocupa bastante mas que uno de MEMS). Es el mismo dato que bloquea la eleccion del FSM. Y confirmar el contorno. | Equipo de electronica de ACSAR
ELEC-04 | cables_rf_moduladores | Coaxiales RF de PCB-2 a los dos moduladores | payload_pcb | drivers_opticos |  | sin geometria | TBD |  |  | 2 |  | TBD | no |  |  |  |  | Un cable no tiene envolvente hasta que se encamina. Lo que hace falta es el diametro del coaxial elegido y su radio minimo de curvatura; con esos dos, el recorrido se dibuja como KEEP-OUT entre PCB-2 y cada modulador, no como un cuerpo. | Equipo de electronica de ACSAR
ELEC-01.1 | qrng_idq20mc1_s3 | QRNG ID Quantique IDQ20MC1-S3 | payload_pcb | control_qkd | ID Quantique IDQ20MC1-S3 | aproximado propio: caja | confirmado | 4.2 x 5.0 x 1.1 | Brief ACSAR 2026-09-19 (cita ficha ID Quantique IDQ20MC1-S3) | 4 |  | TBD | no

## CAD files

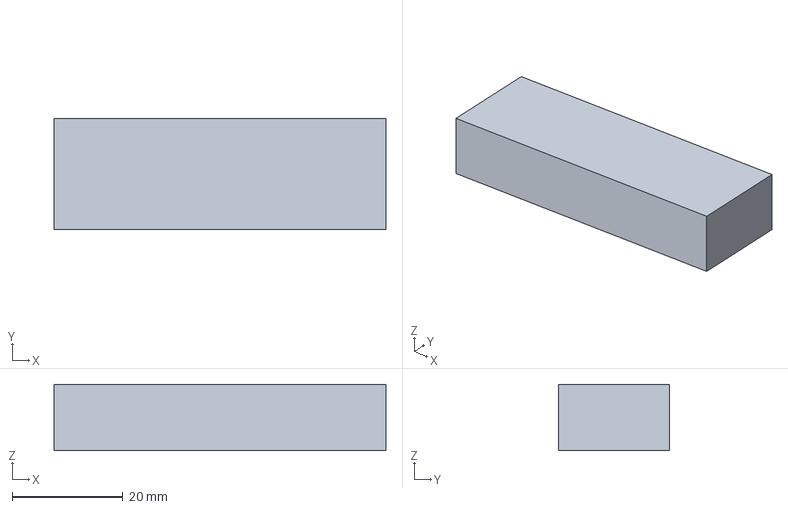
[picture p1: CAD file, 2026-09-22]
cad/generated/acoplador_monitor.step
60.0 x 20.0 x 12.0 mm

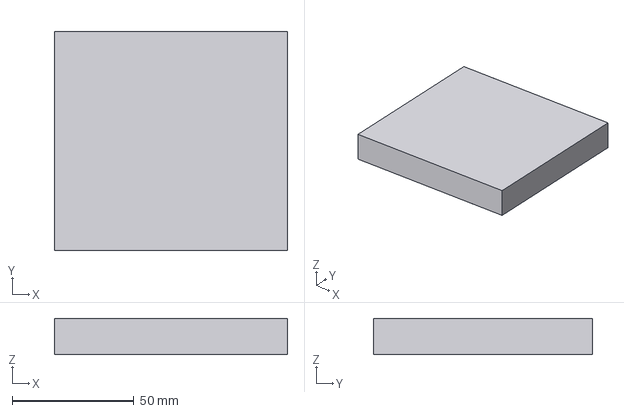
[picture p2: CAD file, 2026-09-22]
cad/generated/subsistemas/drivers_opticos.step
95.9 x 90.2 x 15.0 mm

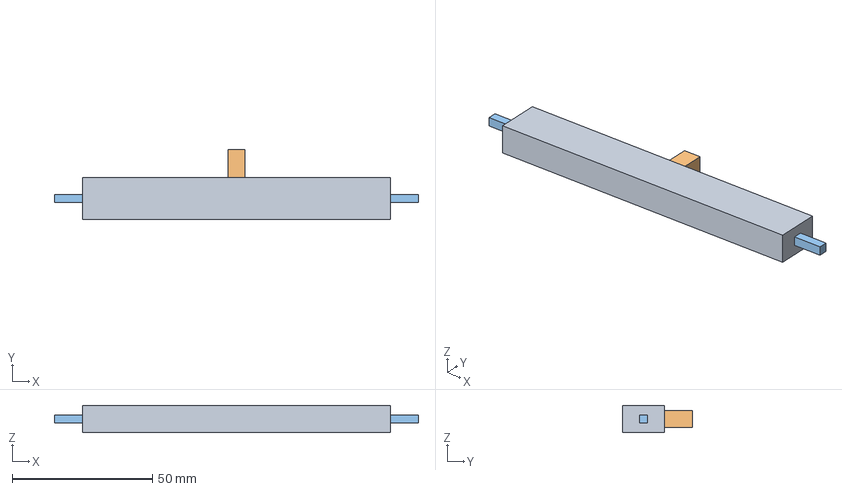
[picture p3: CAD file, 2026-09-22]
cad/generated/mod_fase_mpz_ln_10.step
130.0 x 25.0 x 9.70 mm

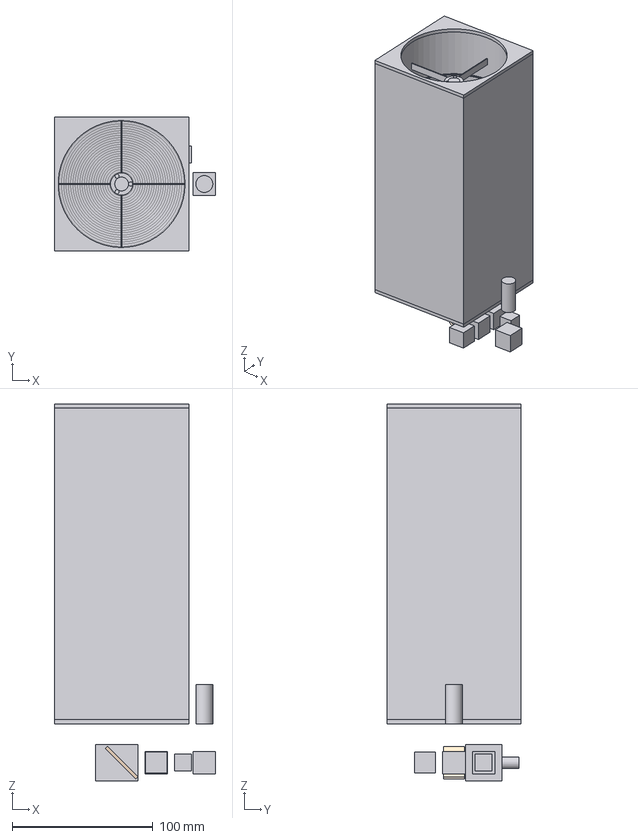
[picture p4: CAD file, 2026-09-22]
cad/generated/subsistemas/terminal_optico.step
114.4 x 95.4 x 267.5 mm
fsm
dicroico_d1
espejo_plegado_cuantico
dicroico_d2
colimador_beacon_bajada
trampa_luz_d1
camara_beacon
fotodiodo_monitor_beacon
colimador
telescopio_cassegrain

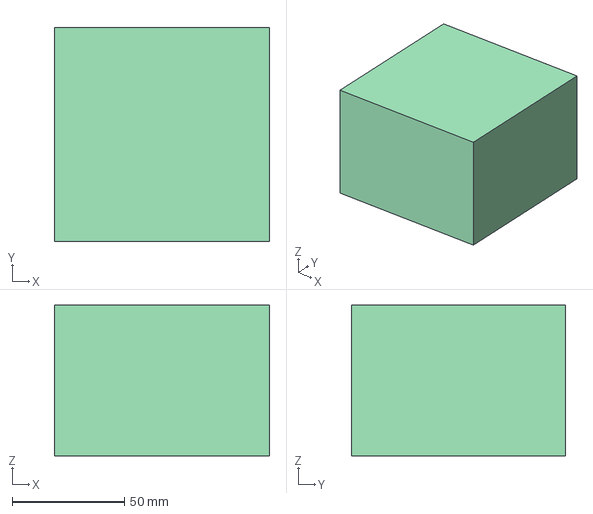
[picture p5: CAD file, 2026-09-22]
cad/generated/subsistemas/ADCS.step
95.9 x 95.4 x 67.3 mm

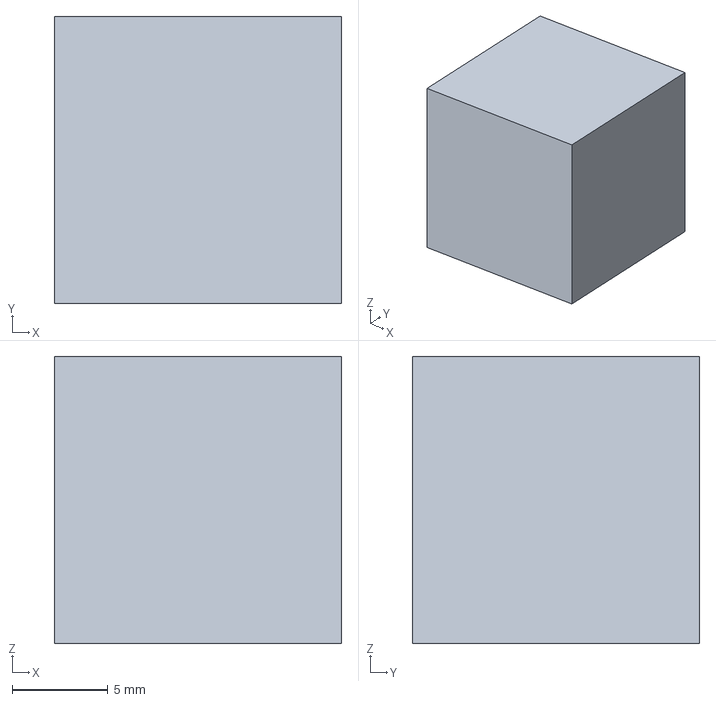
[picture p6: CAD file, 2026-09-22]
cad/generated/trampa_luz_d1.step
15.0 x 15.0 x 15.0 mm

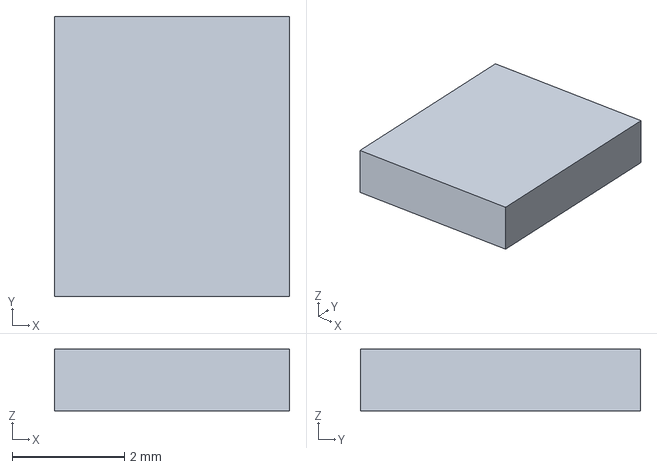
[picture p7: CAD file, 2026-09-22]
cad/generated/qrng_idq20mc1_s3.step
4.20 x 5.00 x 1.10 mm

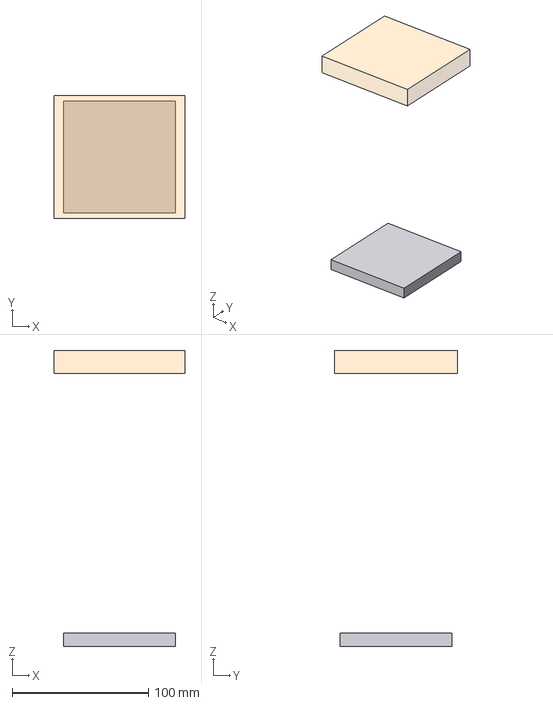
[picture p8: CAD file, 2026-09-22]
cad/generated/subsistemas/comunicaciones.step
96.0 x 90.0 x 217.4 mm
radio_banda_s_quasar_strx
antena_quasar_wsant

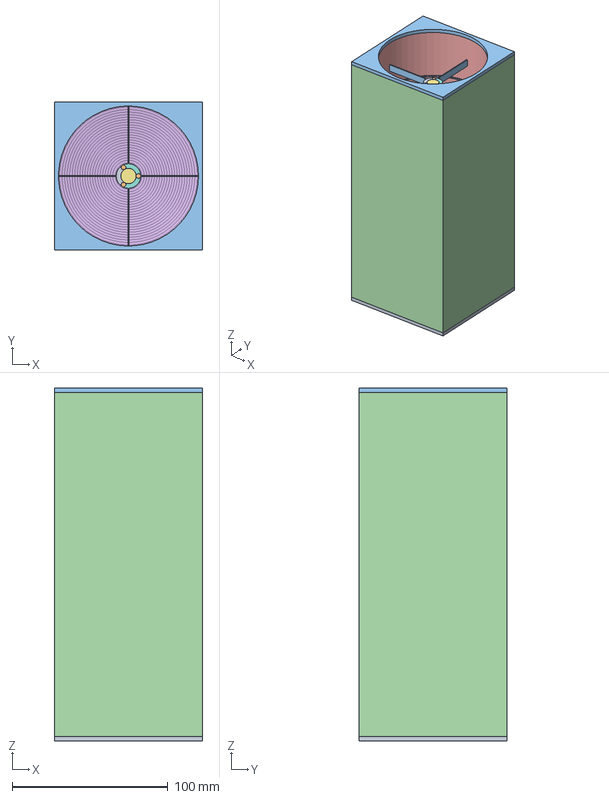
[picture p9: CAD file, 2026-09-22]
cad/generated/telescopio_cassegrain.step
95.4 x 95.4 x 227.0 mm

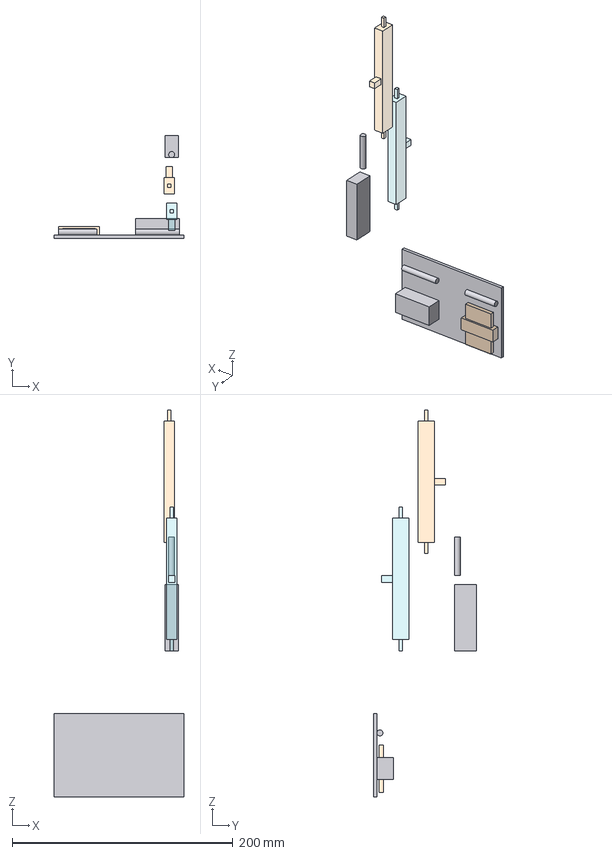
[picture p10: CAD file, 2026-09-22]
cad/generated/subsistemas/bandeja_optica.step
117.7 x 93.2 x 350.4 mm
bandeja_optica
laser_dfb_1550
laser_beacon_bajada
aislador
filtro_espectral
mod_fase_mpz_ln_10
acoplador_monitor
voa
mod_intensidad_mxer_ln_10

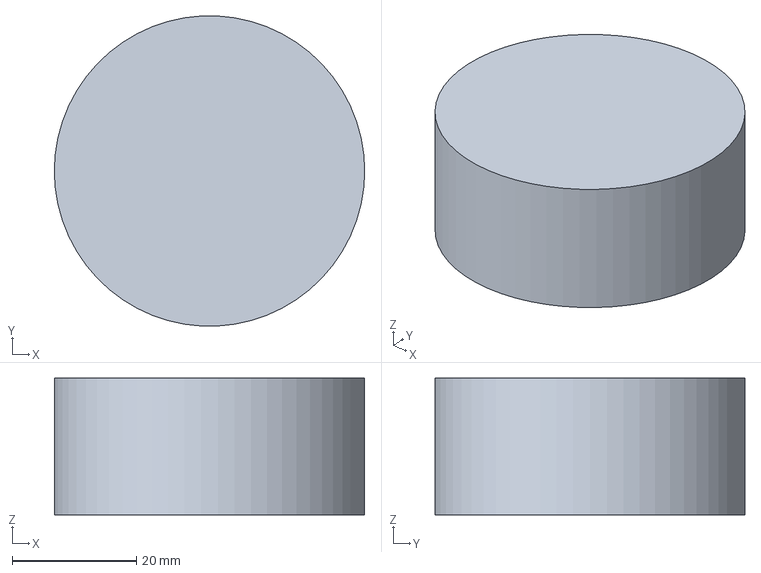
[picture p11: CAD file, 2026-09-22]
cad/generated/fsm_piezo_pi_s331.step
50.0 x 49.9 x 22.0 mm

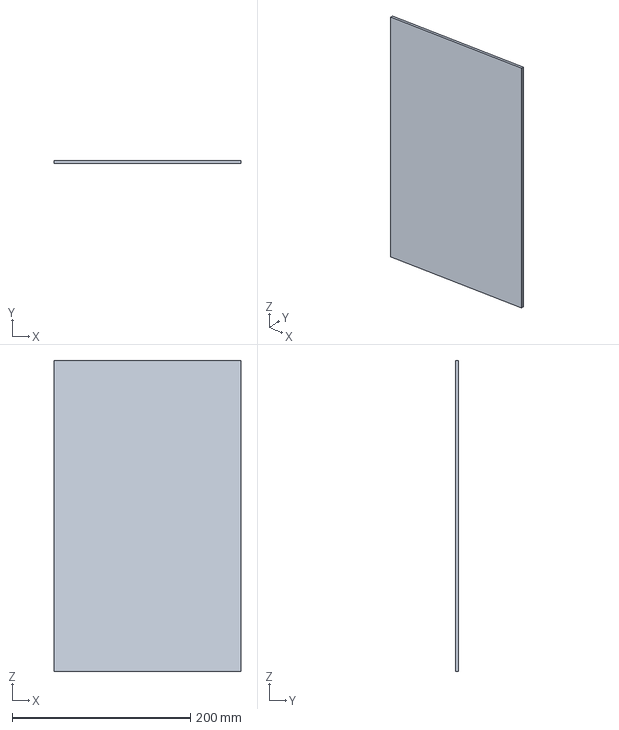
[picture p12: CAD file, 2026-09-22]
cad/generated/paneles_photon_side.step
209.3 x 3.50 x 349.0 mm

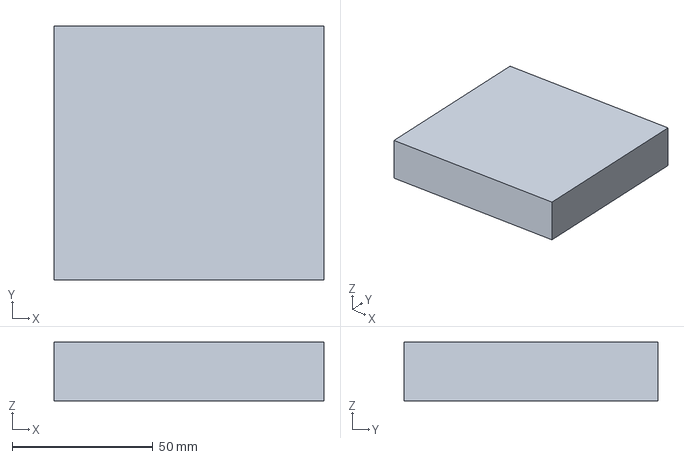
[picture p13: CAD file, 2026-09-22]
cad/generated/eps_starbuck_nano_plus.step
95.9 x 90.2 x 20.8 mm

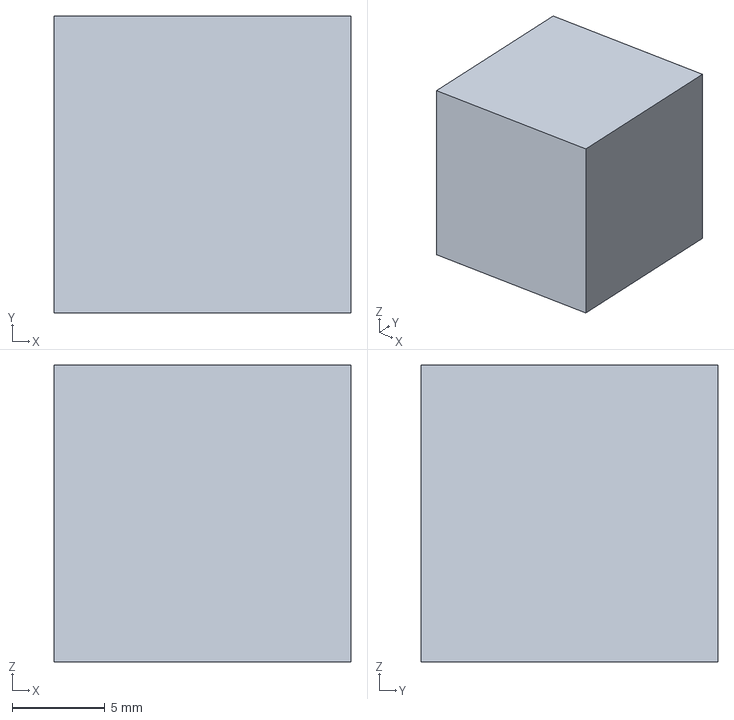
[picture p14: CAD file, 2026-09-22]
cad/generated/dicroico_d1.step
16.0 x 16.0 x 16.0 mm

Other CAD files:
cad/generated/pcb2_drivers_opticos.step
cad/generated/subsistemas/control_qkd.step
cad/generated/subsistemas/pat.step
cad/generated/mod_intensidad_mxer_ln_10.step
cad/generated/adcs_iadcs400.step
cad/generated/aislador.step
cad/generated/antena_quasar_wsant.step
cad/generated/atenuador_fijo.step
cad/generated/bandeja_optica.step
cad/generated/camara_beacon.step
cad/generated/colimador.step
cad/generated/colimador_beacon_bajada.step
cad/generated/dicroico.step
cad/generated/dicroico_d2.step
cad/generated/espejo_plegado_cuantico.step
cad/generated/estructura_6u.step
cad/generated/filtro_espectral.step
cad/generated/fotodiodo_monitor_beacon.step
cad/generated/fsm.step
cad/generated/laser_beacon_bajada.step
cad/generated/laser_dfb_1550.step
cad/generated/pcb1_control_qkd.step
cad/generated/pcb3_pat.step
cad/generated/radio_banda_s_quasar_strx.step
cad/generated/trampa_luz_d2.step
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

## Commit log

2026-09-20 Modelo 3D parametrico y analisis volumetrico del 6U CLAU
    Base del repositorio: estructura 6U segun CDS Rev 14.1, catalogo unico de
    componentes con fuente y estado, ensamblaje exportable a STEP para FreeCAD,
    analisis de volumen/interferencias/conexiones/presupuestos y 40 tests.
    Regla principal aplicada de punta a punta: ningun numero vive en el codigo.
    Las 28 entradas del catalogo llevan valor, unidad, fuente y estado
    (confirmado / referencia / decision / TBD), y la validacion falla si un TBD
    tiene valor, si le falta decir que falta y a quien pedirlo, o si una magnitud
    con valor no tiene fuente. Quedan 49 pendientes y 4 discrepancias, todas
    registradas en vez de resueltas por nuestra cuenta.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
    [adcs_iadcs400.step, bateria_optimus_30.step, clau_6u.step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]
2026-09-20 Fija la distribucion en dos columnas de 3U y coloca las primeras 8 piezas
    Distribucion elegida: dos columnas a lo largo de todo Z, plataforma en -X con
    la pila PC104 completa y payload en +X repartido en telescopio, banco de
    espacio libre y bandeja de fibra. Las cuatro zonas embaldosan exactamente la
    zona util, y hay un test que lo comprueba.
    data/layout.yaml pasa a generarse con tools/generar_layout.py: ninguna
    coordenada se escribe a mano, todas salen del catalogo y del paso PC/104.
    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
    [adcs_iadcs400.step, bateria_optimus_30.step, clau_6u.step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]
2026-09-20 Anade el visor web del ensamblaje y ordena los STEP de proveedor
    `uv run clau3d ver` exporta el ensamblaje a GLB, vuelca a escena.json todo lo
    que la geometria no sabe decir y lo sirve en localhost con un visor three.js.
    El visor es propio y no uno generico de CadQuery porque aqui lo que hay que ver
    no es solo la forma, es de donde sale cada cota y que falta: colorea por estado
    del dato, lista los 19 componentes sin envolvente con a quien pedirselos, marca
    el volumen libre como techo mientras falten envolventes y ensena los chequeos
    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
2026-09-20 new one
    [adcs_iadcs400.step, bateria_optimus_30.step, clau_6u.step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]
2026-09-20 Compacta el GLB del visor y deja de regenerarlo sin motivo
    El visor iba lento por como entrega la geometria OpenCASCADE: una primitiva
    de glTF por cara del BREP. El ensamblaje salia con 38 738 primitivas para
    862 000 triangulos, o sea 38 738 llamadas de dibujo por fotograma, mas 18 MB
    de JSON que analizar y una EdgesGeometry por cada una. El servidor no tenia
    nada que ver: servia los 46 MB por localhost en 15 ms.
    - gltf.compactar() funde las primitivas de cada malla en una por material,
    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
2026-09-20 Anade el estado 'supuesto' al catalogo
    El modelo tenia 19 de 27 componentes sin envolvente, y un ensamblaje con 19
    huecos no se puede comprobar contra nada: ni interferencias, ni volumen libre,
    ni recorridos. Para poder dibujarlos hace falta un numero, y para la mayoria de
    esas piezas no existe ninguno publicado.
    'supuesto' es ese numero, declarado como lo que es. Lleva la carga de los dos
    mundos: exige 'fuente' como cualquier magnitud -- pero ahi va el razonamiento,
    no una ficha -- y exige ademas 'falta' y 'pedir_a' como un TBD, porque el dato
    de verdad sigue sin estar. No suma en los presupuestos de masa ni de potencia,
    se dibuja en gris y mas transparente que lo demas, y sale en la lista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
2026-09-20 Anade formas aproximadas con conectores y el drop-in de STEP
    Tres cosas que hacian falta antes de poder modelar el payload entero.
    **Cilindros.** Media cadena optica es cilindrica -- colimadores, aisladores,
    VOAs, el barrilete del telescopio -- y dibujarlos como cajas infla su volumen
    en un 27% sin que nadie lo vea. Se declaran con su caja envolvente, igual que
    todo lo demas, mas 'forma.eje'; las dos cotas que no son el eje son el diametro
    y 'validar' comprueba que coinciden.
    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
2026-09-20 Modela y coloca la bandeja de fibra entera (OPT-01 a OPT-07, OPT-14)
    Las siete piezas de la cadena de fibra pasan de no existir en el modelo a estar
    dibujadas y colocadas, mas la placa que las sostiene. De 8 piezas colocadas a
    14, y sin una sola interferencia.
    **Lo que si es dato.** El laser DFB se dibuja con el contorno del encapsulado
    BUTTERFLY DE 14 PINES estandar, 37.4 x 12.7 x 7.8 mm, del documento de PHIX:
    es el formato en el que viene el modulo, aunque no sea el plano de Gooch &
    Housego. Y los dos moduladores Exail estrenan sus conectores: el RF sobresale
    10 mm, que es cota del plano, y los protectores de fibra 10 mm por extremo,
    que salen de restar las dos cotas del plano (130 con p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
    [acoplador_monitor.step, aislador.step, bandeja_optica.step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]
2026-09-20 Modela y coloca el banco optico y el telescopio (OPT-08 a OPT-13)
    De 14 piezas colocadas a 20, sin interferencias. El payload entero esta ya
    dibujado salvo las PCBs.
    **El FSM: se modela el MEMS, y eso no es elegirlo.** Mirrorcle publica el
    encapsulado DIP24 ceramico, 30.5 x 15.1 x 2.16 mm, asi que es la opcion con
    cota real y es la que se dibuja. La opcion piezo entra al catalogo como
    'fsm_piezo_pi_s331', marcada 'alternativa_de' para que no sume en nada, y trae
    lo que PI SI publica: 130 g de masa (280 g en la variante de 5 mrad), -20 a
    80 C, espejo de 12.7 x 3 mm. Esos 130 g son el dato que decide: frente a un
    MEMS de gramos, es el argumento fuerte a favor del MEMS, y ahora esta en el
    cata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
2026-09-20 Modela la electronica de payload y cierra la plataforma (ELEC-01..04, PLAT-03, PLAT-07)
    26 piezas colocadas, 0 interferencias. Con esto estan todos los componentes de
    la opcion B en el modelo, dibujados y situados.
    **Las tres PCBs propias dejan de ser huecos.** Contorno PC104 (propuesto, no
    confirmado) y altura SUPUESTA de 15 mm, que es la posicion de separador menos
    holgura. La 'fuente' avisa de la circularidad: comprobar que una de estas
    tarjetas cabe en SU posicion de separador devuelve la hipotesis. Lo que si
    comprueba de verdad es que no choca con las vecinas, cuyas alturas si son
    datos, y eso es justo lo que encontro un problema (abajo). Queda escrito por
    que las tres van en la pila y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
2026-09-20 Genera los keep-outs de fibra, coaxial y haz libre
    `keep_out` llevaba vacio desde el principio, con un comentario que decia por
    que: sin el radio de curvatura, un keep-out seria una medida inventada. Sigue
    siendo verdad, asi que en vez de quitar el comentario se ha quitado el
    problema: ahora un keep-out lleva 'estado' y 'fuente', igual que un numero y
    que un STEP, y los 18 que se dibujan van todos como SUPUESTO con el parametro
    del que salen escrito al lado.
    Los tres parametros viven en el catalogo junto al hueco que NO cierran, con el
    mismo patron que 'paso_apilamiento_modelado': radio de curvatura de fibra
    30 mm, tramo recto de salida 20 mm, radio de coaxial 25 mm, diametro de haz
    10 mm.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
2026-09-20 Anade las salidas por subsistema y la hoja de estado en CSV
    **Un STEP por subsistema**, en cad/generated/subsistemas/. No es un despiece:
    cada fichero lleva las coordenadas del satelite completo, asi que abrir dos a
    la vez los ensena encajados. Sirve para mirar una parte sin cargar los ~550
    solidos del conjunto y para mandarle a alguien solo lo suyo.
    El nombre del fichero dice si se puede versionar. Un STEP de subsistema que
    contenga una pieza dibujada con CAD de fabricante CONTIENE ese CAD, y el
    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
    [ADCS.step, acoplador_monitor.step, adcs_iadcs400.step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]
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2026-09-20 Corrige el recuento de tests en la documentacion
    120, no 115.
2026-09-20 Sustituye el cilindro del telescopio por un modelo parametrico
    El telescopio era un cilindro de reserva de 95.4 x 95.4 x 200 mm. Ahora es un
    modelo completo -- barrilete, primario y secundario conicos por revolucion,
    arana, baffles, celda isostatica, brida al FSM y camino del haz -- construido
    en src/clau3d/optica/ desde un bloque 'optica' nuevo del catalogo.
    No sube de estado: sigue siendo SUPUESTO (gris, transparente, sin sumar en
    masa) y sigue siendo el fallback del STEP de Aperture Optical Sciences. Los 33
    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
    [acoplador_monitor.step, adcs_iadcs400.step, aislador.step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]
2026-09-20 Modela el brazo de los beacons con dos dicroicos
    El beacon de bajada estaba en el catalogo y en el layout pero no funcionaba y
    no estaba conectado: la camara en Y = +31.5 y el laser en Y = -31.5, en lados
    OPUESTOS del dicroico, asi que un laser que emitia hacia +Y contra la cara
    trasera no tenia camino hacia el FSM. Y en connections.yaml el beacon de bajada
    no tenia ni una conexion declarada.
    Arquitectura nueva (decision de ACSAR, 2026-09-20): los dos beacons comparten
    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
    [components_status.csv]
2026-09-21 Reordena la cadena optica y mueve la frontera de la codificacion
    La cadena declarada ponia el aislador, el filtro, el VOA y el acoplador
    DETRAS del codificador de polarizacion. Eso no es una cadena peor: un
    aislador PM transmite un solo eje y proyecta los cuatro estados BB84
    sobre el mismo, o sea que borra la codificacion entera. Y cualquier
    fibra PM detras del codificador le mete a los estados diagonales -- que
    no son autoestados -- una fase que deriva con la temperatura: una base
    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
    [ADCS.step, acoplador_monitor.step, aislador.step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]
2026-09-21 Corrige el margen del banco citado en 4.7(b)
    Era 7.7 mm y desde que el colimador salio de esa fila son 15.7.
2026-09-21 Redistribuye el payload: telescopio a 227 mm y haz a 7 mm
    Los dos "no cabe" que quedaban abiertos -- el brazo de los beacons (6.8 mm)
    y el tramo recto post-codificacion (18.0 mm) -- eran el mismo problema visto
    por dos sitios: el payload estaba repartido con las longitudes de la
    arquitectura anterior. `clau3d informe` devuelve 0 por primera vez desde que
    se dibuja el payload entero, y las 31 piezas estan colocadas.
    Cinco decisiones de ACSAR (2026-09-21), todas con estado 'decision' o
    'supuesto' y su razonamiento en el catalogo:
    * longitud_reservada del telescopio 200 -> 227 mm, que son los "~2U" de
    verdad del brief con la U de longitud de la CDS. La franja mide lo mismo
    que esa reserva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
    [ADCS.step, acoplador_monitor.step, adcs_iadcs400.step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]
